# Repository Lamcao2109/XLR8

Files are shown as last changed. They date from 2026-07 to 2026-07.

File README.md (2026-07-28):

# XLR8 — WRO 2026 Future Engineers

Engineering documentation for **XLR8**, a self-driving LEGO SPIKE Prime vehicle built for the **World Robot Olympiad (WRO) 2026 — Future Engineers** category.

> CAD/3D-printable model files are in [`models/`](models/).

## Repository content

| Folder | Content |
|---|---|
| [`t-photos`](t-photos/) | Team photos (official + funny) |
| [`v-photos`](v-photos/) | 6 photos of the vehicle — front, back, left, right, top, bottom |
| [`video`](video/) | Links to the driving-demonstration videos (open + obstacle rounds) |
| [`schemes`](schemes/) | Electromechanical wiring diagram and annotated component photos |
| [`src`](src/) | Control software (hub + camera) |
| [`models`](models/) | 3D-printable/CAD parts (CAD source + STL/STEP + full render) |
| [`construction-guide`](construction-guide/) | Step-by-step build guide (rear camera → upper chassis → lower chassis → software) |
| [`other`](other/) | Supporting figures referenced from this document (mechanical design, iteration history, power & sensors, software & vision) |

---

## Table of contents

1. [Our team](#1-our-team)
2. [The robot](#2-the-robot)
3. [Mobility and Mechanical Design](#3-mobility-and-mechanical-design)
4. [Power and Sensor Architecture](#4-power-and-sensor-architecture)
5. [Software Architecture and Obstacle Strategy](#5-software-architecture-and-obstacle-strategy)
6. [Systems Thinking and Engineering Decisions](#6-systems-thinking-and-engineering-decisions)
7. [Repository / build instructions](#7-repository--build-instructions)
8. [Future Improvements](#8-future-improvements)
9. [Conclusion](#9-conclusion)

---

## 1. Our team

This repository documents the autonomous robot car developed by **XLR8** for the **2026 World Robot Olympiad Future Engineers** competition. The project was designed, built and programmed by a team of three students.

| Photo | Member | Role |
|---|---|---|
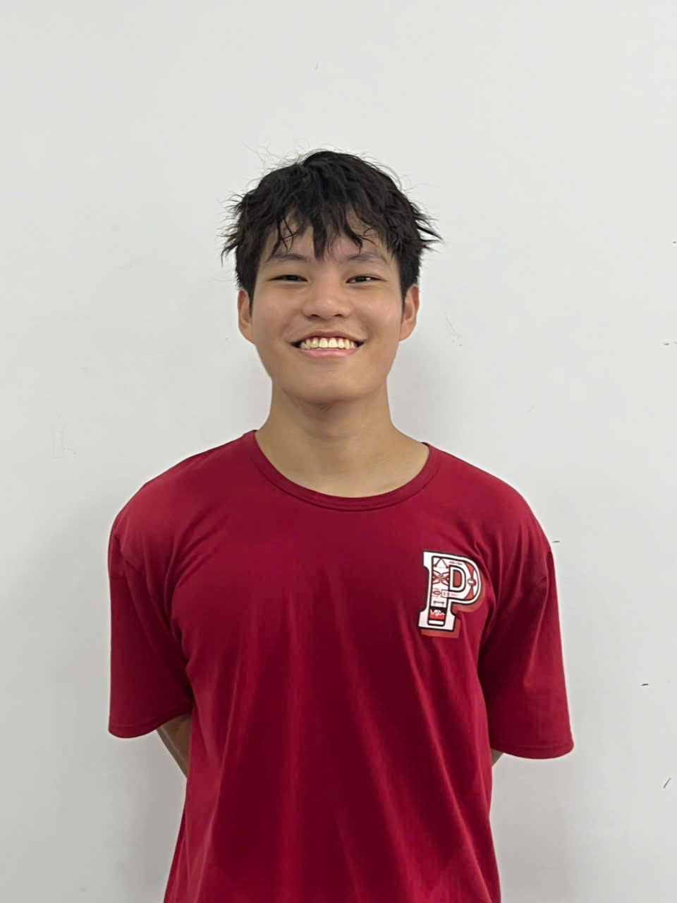
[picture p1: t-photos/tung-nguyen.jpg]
Tung Nguyen
|  | **Tung Nguyen (Philip)** | 17-year-old student from Vietnam. Responsible for documenting the team's development process and photography. Interests: engineering, physics, teamwork, volleyball, video games. |
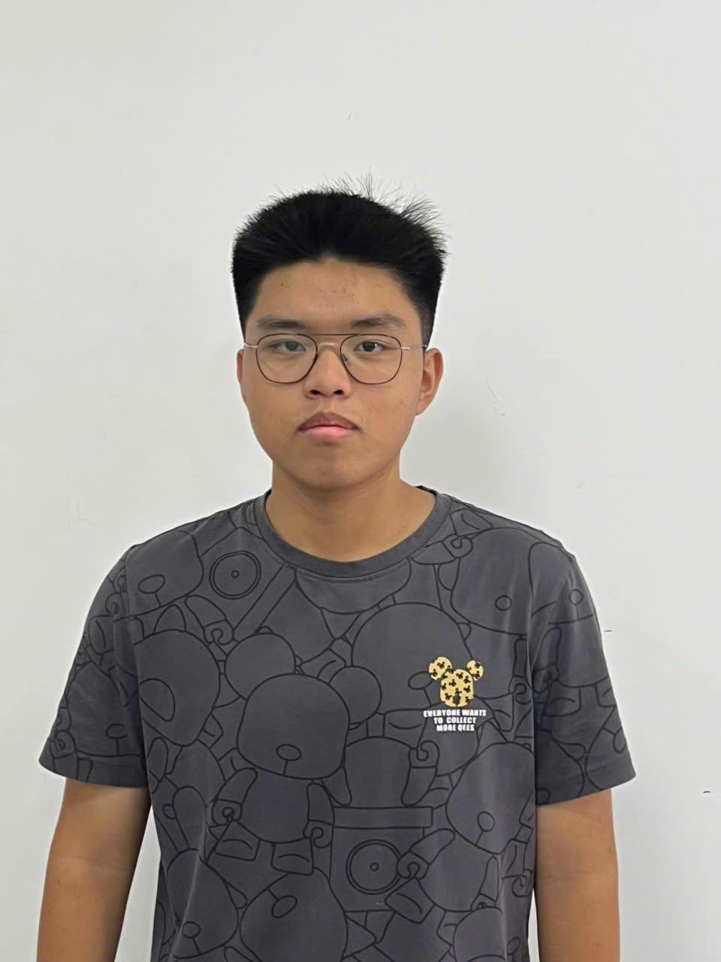
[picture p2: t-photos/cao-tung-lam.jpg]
Cao Tung Lam
|  | **Cao Tung Lam** | Lead mechanical builder — brings prior WRO experience (WRO 2023, 2024, 2025) and designed/assembled the chassis. |
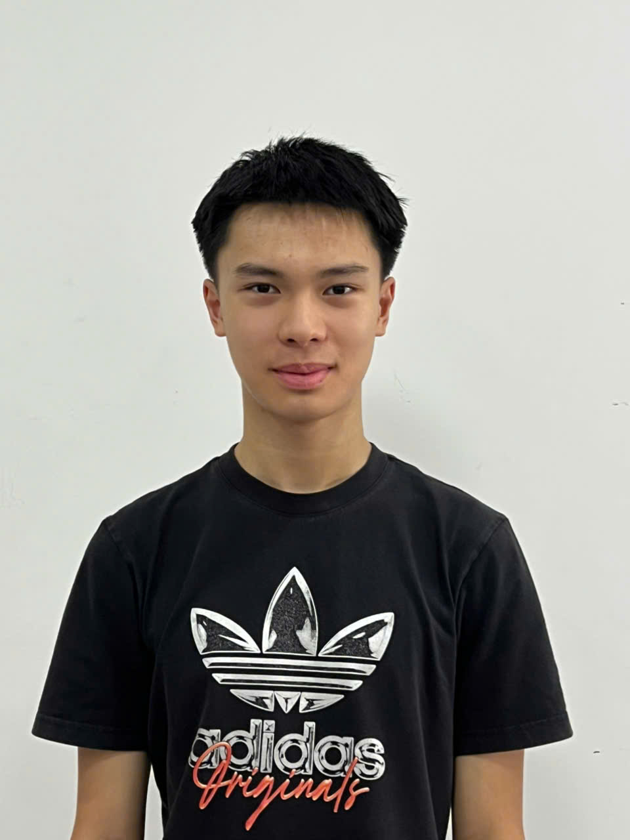
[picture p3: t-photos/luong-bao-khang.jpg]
Luong Bao Khang
|  | **Luong Bao Khang** | Senior WRO participant — competed at the international finals in 2023, 2024 and 2025. |

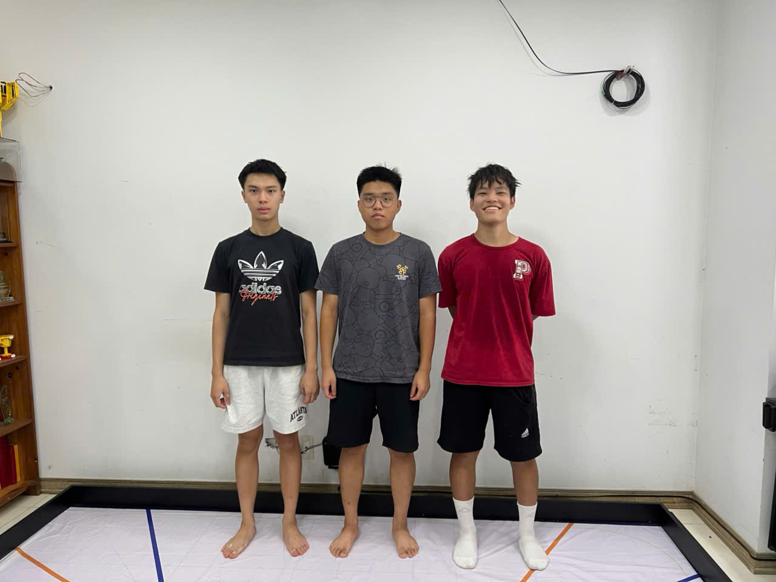
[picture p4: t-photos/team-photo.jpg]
Team photo


Last year's robot (which inspired this year's chassis) is documented at: https://github.com/uyennhu25/WRO_2025_Future_Engineers

## 2. The robot

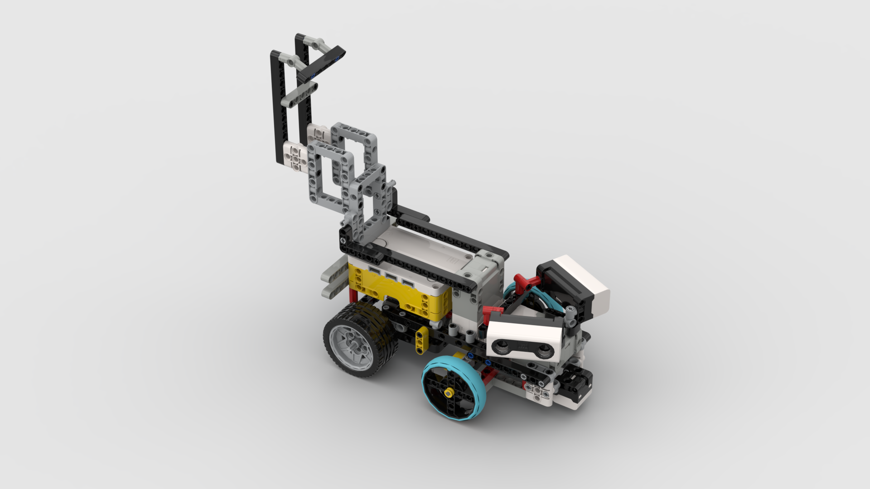
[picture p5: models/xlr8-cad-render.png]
Full CAD render


CAD source and 3D-printable parts for the assembly above are in [`models/`](models/).

| | | |
|---|---|---|
| Front | Back | Top |
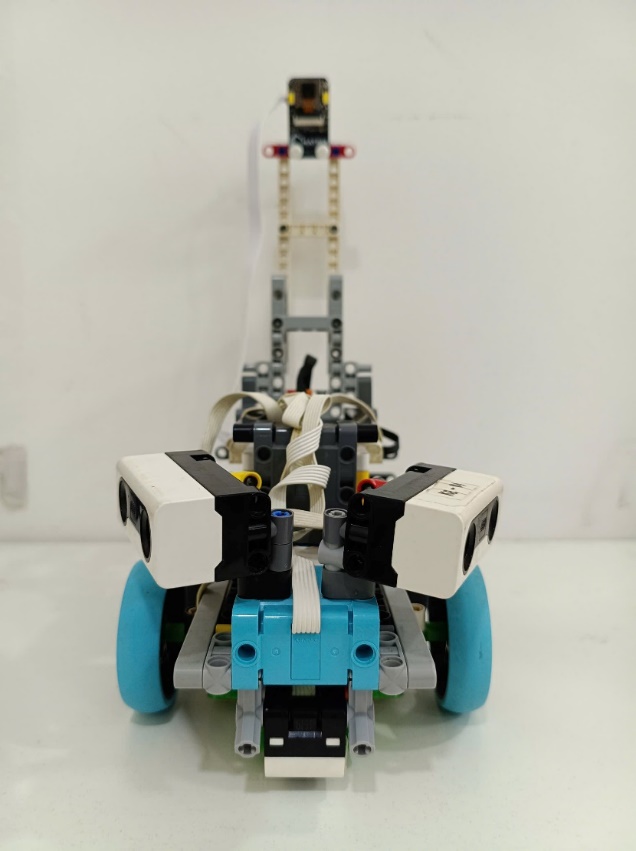
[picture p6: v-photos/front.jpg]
Front view
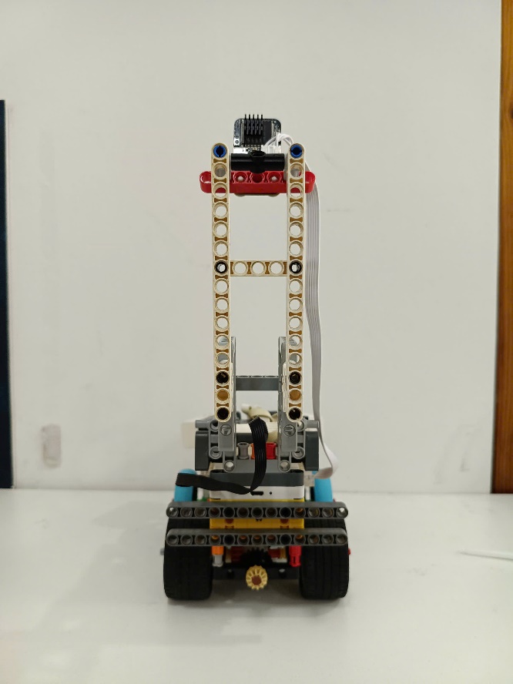
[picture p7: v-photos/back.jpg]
Back view
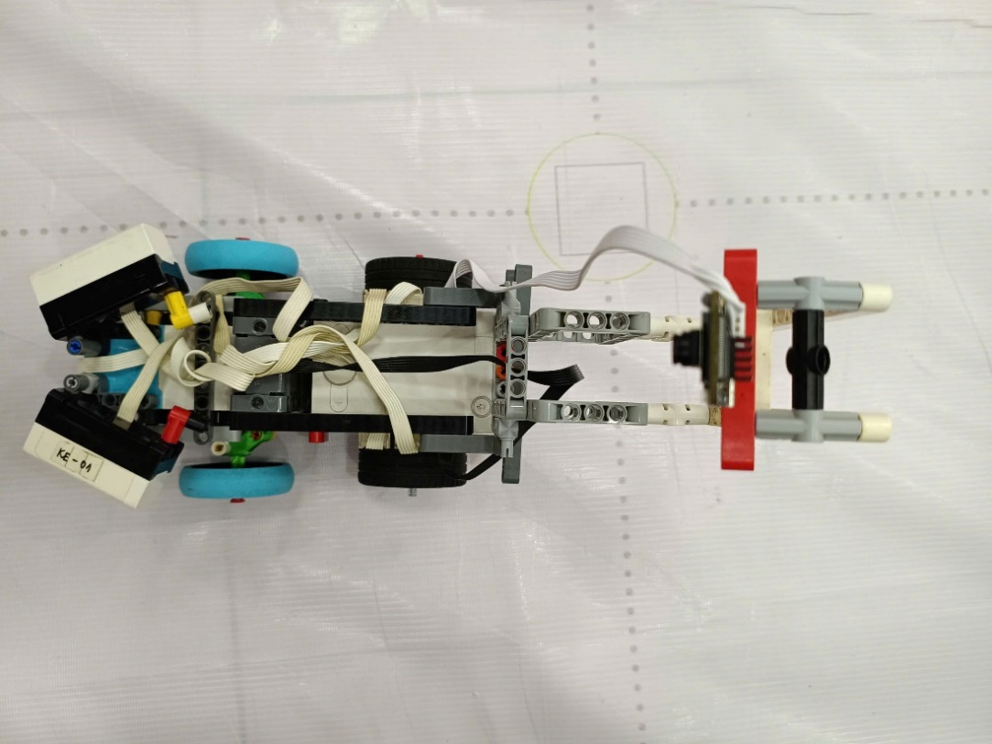
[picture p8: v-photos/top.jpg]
Top view
|  |  |  |
| Left | Right | Bottom |
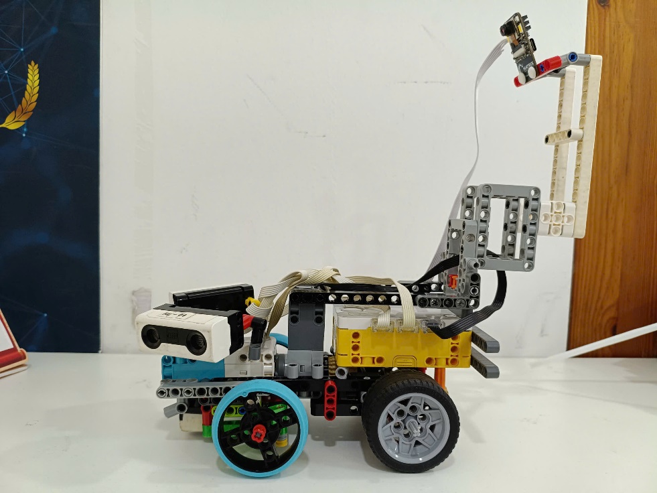
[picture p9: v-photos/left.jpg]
Left view
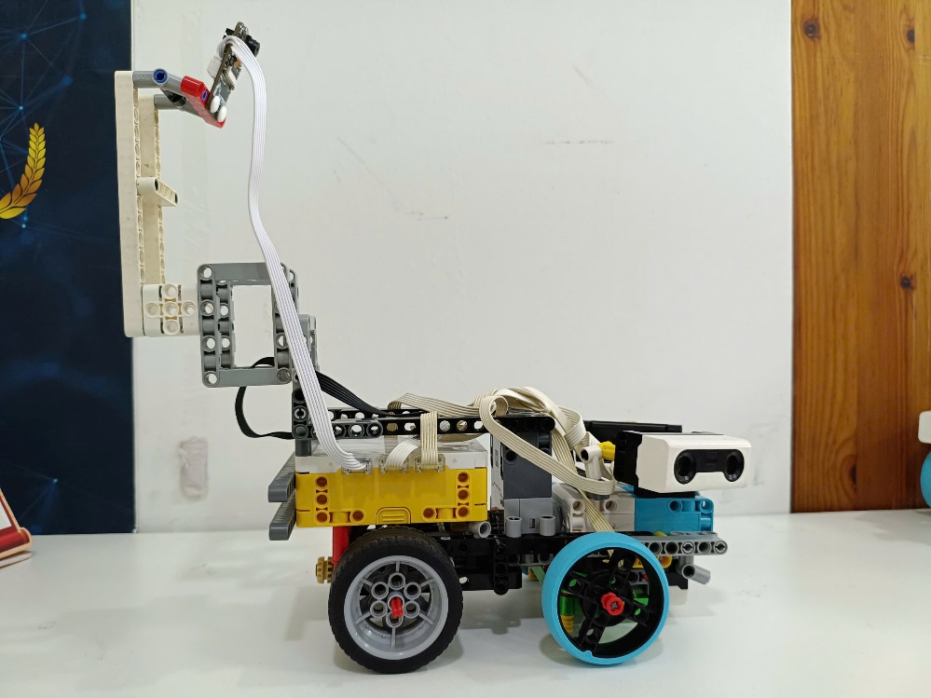
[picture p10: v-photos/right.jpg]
Right view
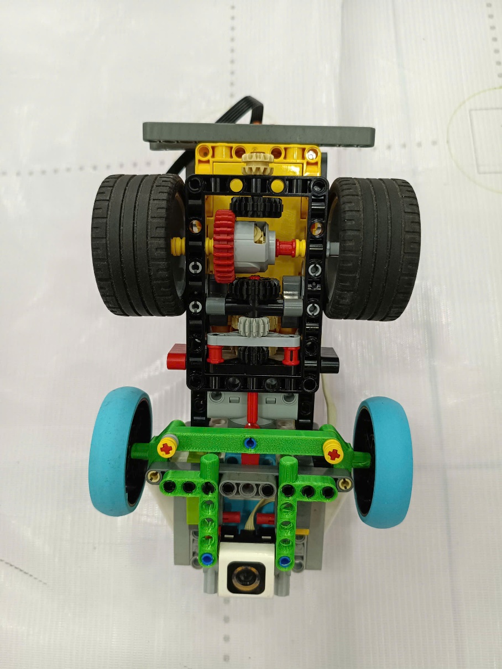
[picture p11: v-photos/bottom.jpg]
Bottom view
|  |  |  |

## 3. Mobility and Mechanical Design

### Design objective

The chassis was designed to remain stable, operate efficiently and make optimal use of available space: a balanced center of gravity for stability during sharp turns/acceleration and a steady camera platform, a lightweight structure to reduce motor load, and compact dimensions for maneuverability.

Lam (our lead builder) competed with a LEGO-based robot in WRO 2023, 2024 and 2025; that experience — and last year's robot — was the starting point for this year's chassis, which was then substantially redesigned.

### Overall chassis layout

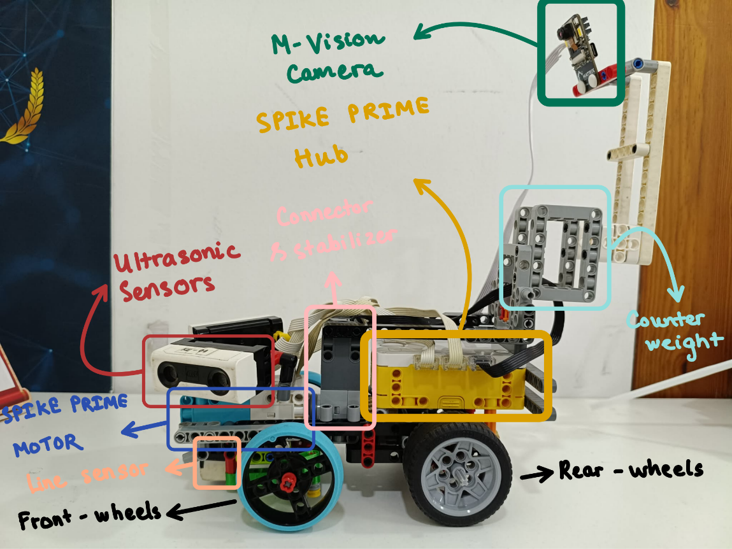
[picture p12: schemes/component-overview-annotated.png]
Component overview


The robot is divided into two main sections:

* **Main chassis** — LEGO SPIKE Prime Hub, drive/steer motors, ultrasonic sensors, line sensor, connector/stabilizer, wheel assemblies.
* **Rear-mounted camera assembly** — counterweight, camera support mast, M-Vision camera.

Unlike last year's design (camera mounted at the front, everything on one chassis), this year's robot elevates the camera on a rear mast:

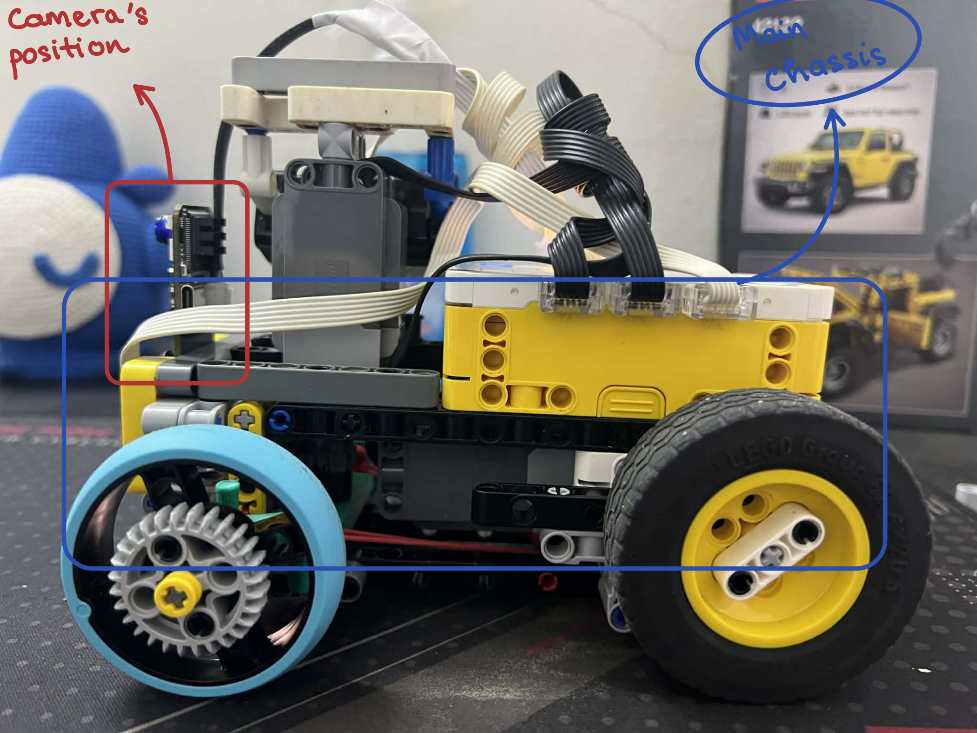
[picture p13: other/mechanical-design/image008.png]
Camera repositioning rationale


Relocating the camera to an elevated rear position gives the vision system a wider field of view, so the corridor and obstacles are detected earlier and more reliably, at the cost of having to keep the tall mast from destabilizing the car.

### Keeping the elevated camera from tipping the car

We ran a simple static-moment analysis, taking the rear-wheel ground contact line as the pivot, comparing the **overturning moment** created by the rear-mounted mast/counterweight assembly against the **restoring moment** created by the main chassis:

$$M_1 = \sum m_1 \times L_1 \qquad \text{(restoring moment, main chassis)}$$

$$M_2 = \sum m_2 \times L_2 \qquad \text{(overturning moment, rear assembly)}$$

The car does not tip as long as:

$$M_1 \ge M_2 \quad\Longleftrightarrow\quad \sum m_1 L_1 \ \ge\ \sum m_2 L_2$$

Because $\sum m_1 L_1$ is essentially fixed (motors/sensors/hub have fixed mass and position), the only lever we have is the rear assembly: we minimized both the mass $m_2$ and the distance $L_2$ of the rear assembly from the pivot. The box-shaped camera mount (most of the rear assembly's weight) sits as close to the pivot as practical, and the mount itself is a **closed-box structural member** that doubles as counterweight and torsional stiffener.

### What we kept from last year's robot

* **Chassis material** — LEGO Technic/SPIKE parts (lightweight, durable, modular, fast iteration) supplemented with custom **PLA 3D-printed** parts where no suitable LEGO part existed.
* **Wheel choice** — 62.3 mm Technic tires on the rear axle (larger diameter/width → better traction and acceleration) and 49.5 mm SPIKE Prime wheels on the front axle (smaller diameter → sharper steering response).

### Drive and steering mechanism

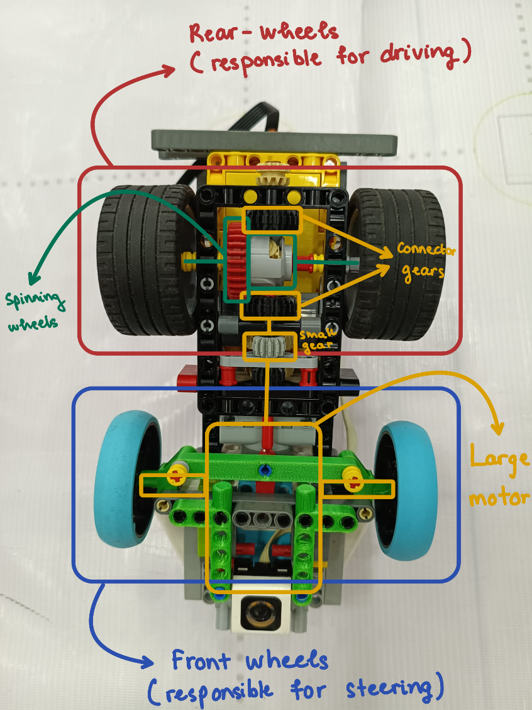
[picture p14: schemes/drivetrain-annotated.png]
Drivetrain


**Rear-wheel drive (RWD).** The rear wheels are powered by a LEGO SPIKE Prime Large Angular Motor through a small gear → two larger gears → final drive gears reduction; the front wheels only steer, driven by a second Large Angular Motor via UART-controlled servo positioning.

We deliberately rejected **front-wheel drive**, even though the drive motor sits over the front wheels and FWD would need no rear power transmission: combining steering and propulsion on the same wheels reduces steering precision and causes understeer in fast corners. Separating the two gives more predictable handling and simplifies implementing Ackermann geometry.

**Ackermann steering.** During a turn the inner and outer front wheels trace circles of different radii, so they need different steering angles (inner wheel turns sharper). Our linkage approximates this so all wheels roll with minimal lateral scrub, improving turn accuracy and reducing friction.

*The geometric reason: one turn, one centre.* When a vehicle corners without any wheel sliding sideways, every wheel travels along a circular arc, and all those arcs share a single centre — the instantaneous centre of rotation (ICR). A wheel rolls cleanly only when its axis points straight at the ICR, so the perpendicular from every wheel must pass through that one point. Our rear axle is fixed, so both rear wheels' axes lie on the same line, which forces the ICR onto the extension of that line. The two front wheels must then angle so their perpendiculars meet at that same spot — and because the inner front wheel sits closer to the ICR, it rides a tighter circle and needs a larger steering angle. That's the whole idea: the front wheels must not be parallel.

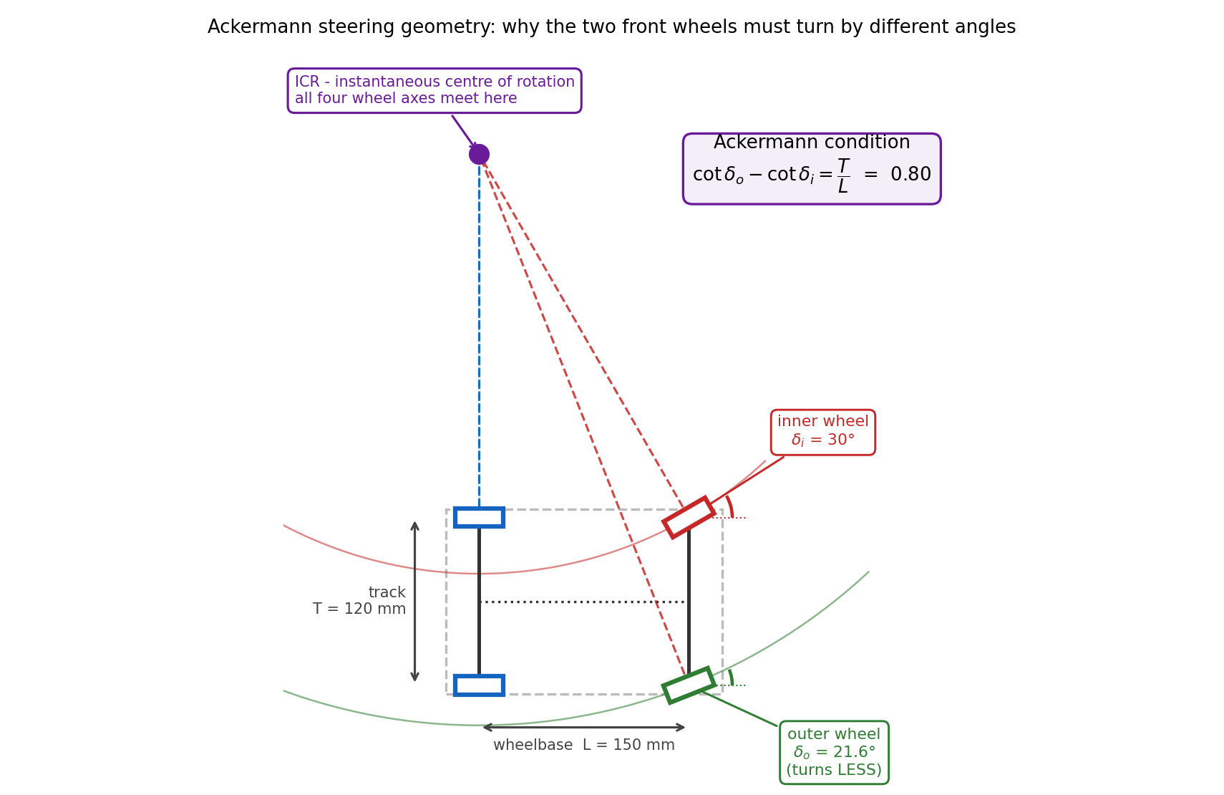
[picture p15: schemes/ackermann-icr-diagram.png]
Ackermann ICR diagram


*Figure — the ICR condition, worked numerically.* The dashed lines are the extended wheel axes: the rear pair (fixed, driven) meets the front pair exactly at the ICR, which is why the ICR always sits somewhere on the rear-axle line. For a wheelbase $L = 150$ mm and track $T = 120$ mm, an inner-wheel angle of $\delta_i = 30°$ requires an outer-wheel angle of $\delta_o = 21.6°$ — not $30°$. Plugging both into the condition confirms it: $\cot(21.6°) - \cot(30°) = 2.53 - 1.73 = 0.80 = T/L$. The two red/green arcs are the actual paths the inner and outer tyres trace; they're concentric about the ICR, which is the entire point — no tyre has to slip sideways to stay on its arc.

*The condition, stated exactly.* With wheelbase $L$, track $T$, and inner/outer steering angles $\delta_i$, $\delta_o$, requiring both perpendiculars to meet on the rear-axle line reduces to:

$$\cot(\delta_o) - \cot(\delta_i) = \frac{T}{L}$$

The cotangent form matters: the required angle difference isn't constant. At a gentle 10° steer our measured geometry differs by about 1°; at 30° (near full lock) it's over 8°. A design that just held both wheels parallel would be almost right while cruising and badly wrong exactly when it matters most — a tight corner or the parking manoeuvre.

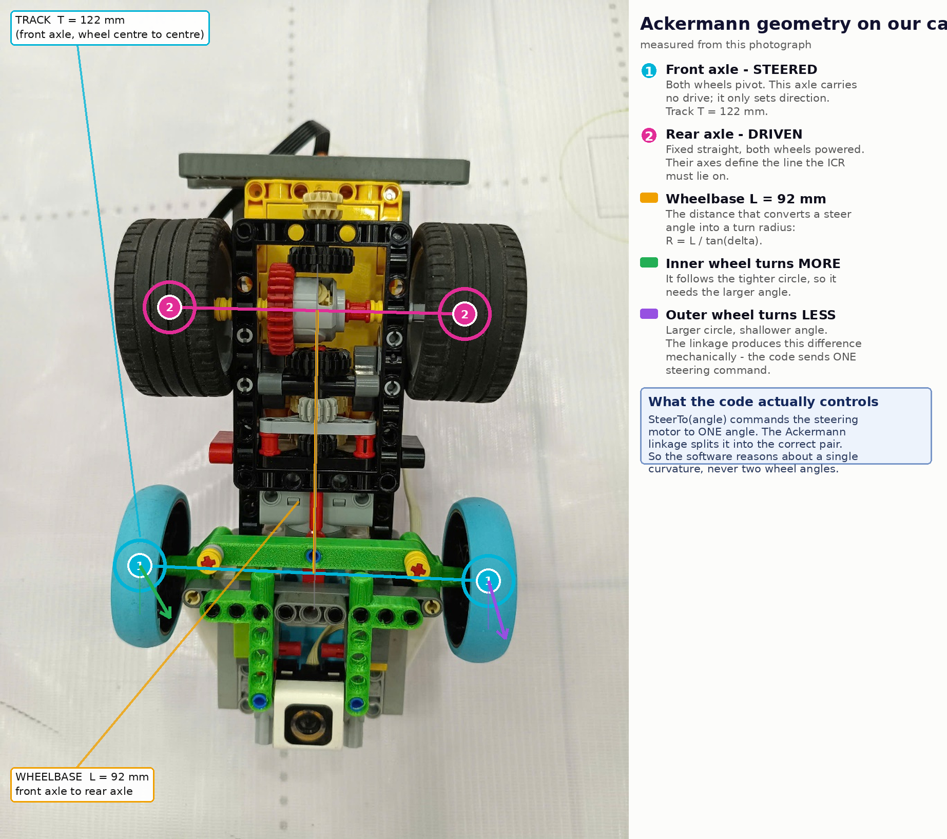
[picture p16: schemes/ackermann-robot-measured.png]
Ackermann geometry measured on our robot


*Figure — the same geometry on our own vehicle, measured from the underside.* Track $T = 122$ mm and wheelbase $L = 92$ mm, giving $T/L \approx 1.33$ — a shorter wheelbase relative to track than the worked example above, so our robot needs an even *larger* angle spread between the two front wheels for the same inner-wheel angle. The front axle (steered, undriven) only sets direction; the rear axle (fixed, driven) defines the line the ICR must lie on. The green arrow marks the inner wheel turning further, the purple arrow the outer wheel turning less — both driven by the single `SteerTo(angle)` command through the physical linkage, not computed separately in code.

*Why it matters for this robot specifically.* Violating the condition forces at least one tyre to scrub sideways instead of roll, which (1) wastes motor torque as friction/heat, slowing the car in corners, (2) wears the tyres unevenly, causing inconsistent lap times late in a run, and (3) makes the turn radius unpredictable — the car no longer follows the arc the steering angle implies. Every dead-reckoned manoeuvre in the code (the escape turn, corner assist, and above all the reverse arcs of the parallel park, §8) assumes a given steering angle produces a *repeatable* radius; Ackermann geometry is what makes that assumption true.

*What this means for the software.* The program never computes $\delta_i$ and $\delta_o$ — the linkage solves the Ackermann relationship mechanically, not the hub numerically. `SteerTo(angle)` sends one number to one steering motor, and the linkage geometry converts it into the correct pair of wheel angles automatically. This is why `CalibrateSteer()` (§5, Change 5) matters so much: since one command drives both wheels through a fixed linkage, the only thing the software has to get right is where the linkage's true centre lies — exactly what the end-stop sweep measures.

### Motor power tuning

We swept motor power at 60/85/100% over 20 test laps on the Open Challenge course, recording lap time, lap-completion rate and braking distance:

| Setting | Motor power | Avg lap time | Lap completion | Braking distance |
|---|---|---|---|---|
| A | 60% | 40.42 s | 95% | 4 cm |
| **B (chosen)** | **85%** | **23.34 s** | **85%** | **6 cm** |
| C | 100% | 18.78 s | 55% | 10 cm |

100% power was fastest but failed 45% of runs — worthless in competition, since a failed run scores zero. 85% power is only ~19.5% slower than 100% but far more reliable, so **85% power** was selected for both the Open and Obstacle rounds.

### Iterative build process

We built a working prototype first, tested on the real field, found concrete failures, and iterated. Photos of that progression are in [`other/iteration-history/`](other/iteration-history/) (version 1 → version 2 → final chassis).

## 4. Power and Sensor Architecture

### Sensor overview

| Sensor | Model | Qty | Purpose |
|---|---|---|---|
| Camera | Matrix Robotics M-Vision Cam (Type-C) | 1 | Lane/sign detection, corner detection |
| Ultrasonic | LEGO SPIKE Prime Ultrasonic Sensor | 2 | Left/right wall distance |
| IMU | Built into SPIKE Prime Hub | 1 | Angular velocity for heading estimation |
| Motor encoders | Built into SPIKE Prime motors | 2 | Distance measurement, steering calibration |
| Color/line sensor | SPIKE Prime color/distance sensor | 1 | Corner line (orange/blue) detection |

### Why each sensor was chosen

**Camera — Matrix Robotics M-Vision Cam.** Connects directly to the hub over Type-C and speaks the SPIKE Prime vision-sensor protocol, so no custom UART implementation or adapter board was needed (unlike an OpenMV Cam H7, a Raspberry Pi camera, or a USB webcam, all of which were considered and rejected for requiring extra hardware/wiring/power).

**Ultrasonic — LEGO SPIKE Prime Ultrasonic Sensor** (5–200 cm range, ~15° cone). Chosen over HC-SR04 (needs a separate microcontroller), ToF VL53L0X (shorter range, light-sensitive, pricier) and LiDAR (overkill, heavy, expensive) because it plugs directly into the hub.

**IMU — built into the hub.** We only read raw `hub.imu.angular_velocity(Axis.Z)`, feeding our own [Lagrange-interpolated heading estimator](#change-6--lagrange-interpolated-theta-from-angular-velocity) instead of the firmware's `hub.imu.heading()` (see §6). An external IMU (e.g. MPU-6050) would add weight, wiring and complexity for no benefit.

**Motor encoders.** Used for `DriveDeg()` (dead-reckoning distance), `CalibrateSteer()` (measuring the full steering range so "straight" is a measured fact, not an assumption) and `SteerTo()` (closed-loop steering angle).

**Color sensor.** Counts the orange/blue corner lines painted on the mat — 12 line events = 4 corners × 3 laps. Kept as a *dedicated* sensor rather than pulling corner counts out of the camera feed, since the camera is already busy with lane/sign detection.

### Power architecture

All components are powered from the SPIKE Prime Hub's own 7.3 V Li-Ion battery — one battery, simpler wiring, less weight.

| Component | Voltage | Current (typical) | Current (peak) | Power (typical) |
|---|---|---|---|---|
| SPIKE Prime Hub | 7.2 V | 1.0 A | 1.5 A | 7.2 W |
| M-Vision Camera | 5 V (Type-C) | 0.15 A | 0.3 A | 0.75 W |
| Ultrasonic ×2 | 5 V (from hub) | 0.04 A | 0.06 A | 0.2 W |
| Drive motors ×2 | 7.2 V | 1.0 A | 2.0 A | 7.2 W |
| **Total** | | **2.19 A** | **3.86 A** | **15.35 W** |

Peak current (3.86 A) occurs during acceleration and hard cornering; the hub's battery comfortably covers the ~3-minute competition round.

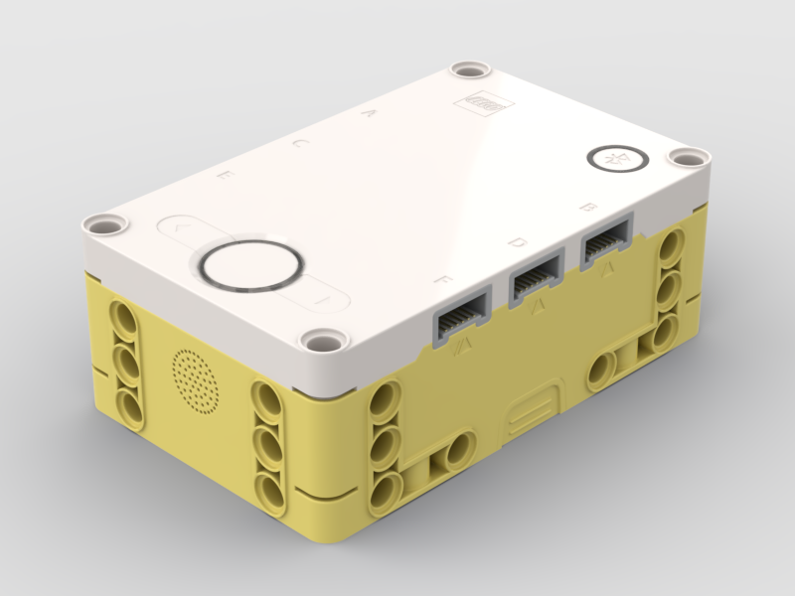
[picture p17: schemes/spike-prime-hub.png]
SPIKE Prime Hub


### Electromechanical wiring diagram

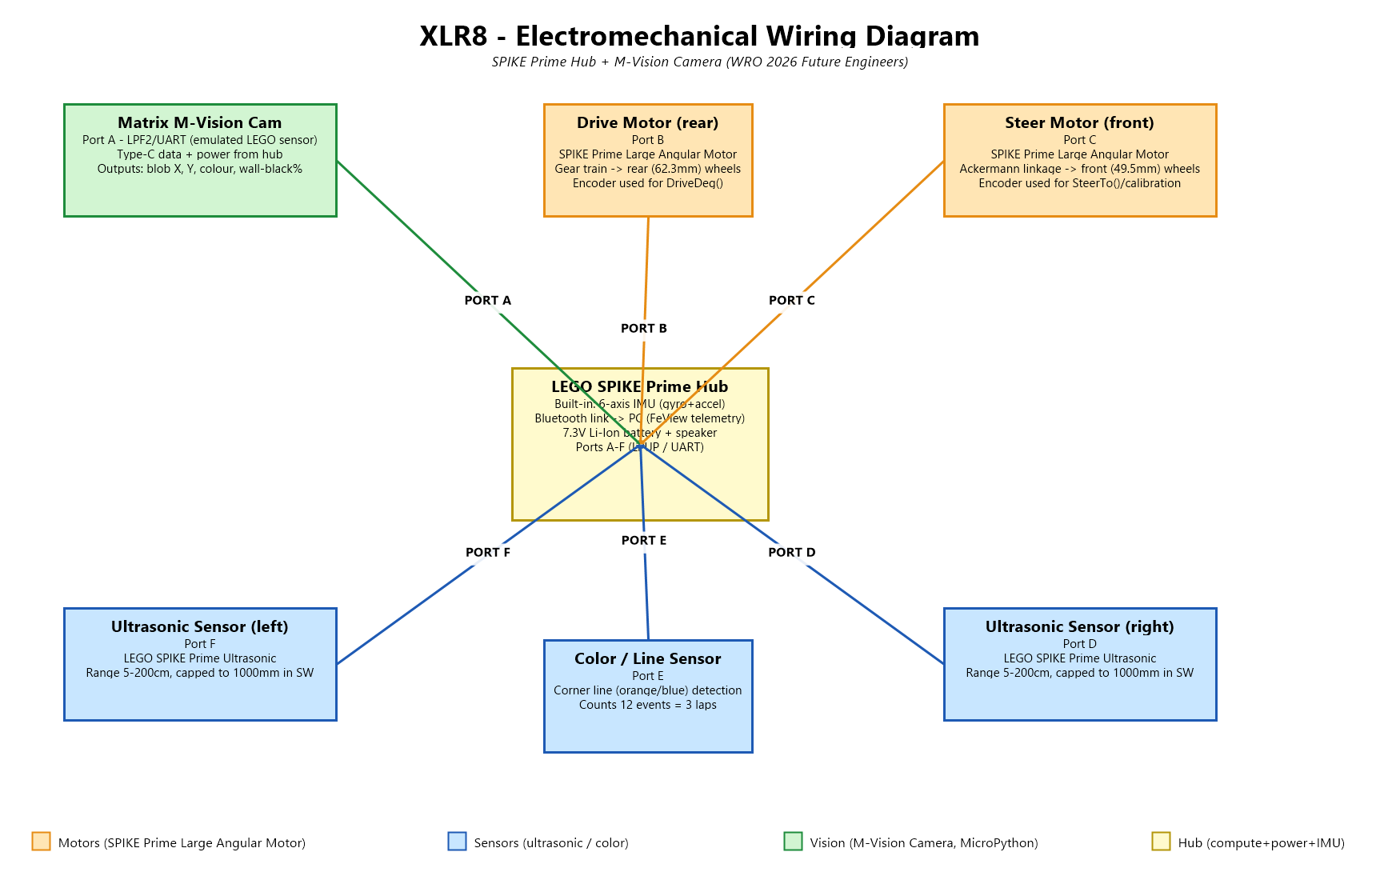
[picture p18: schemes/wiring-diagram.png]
Wiring diagram


| Hub port | Device |
|---|---|
| **A** | M-Vision Camera (LPF2/UART, emulated LEGO sensor over Type-C) |
| **B** | Drive motor → rear wheels |
| **C** | Steer motor → front wheels (Ackermann linkage) |
| **D** | Ultrasonic sensor (right) |
| **E** | Color/line sensor |
| **F** | Ultrasonic sensor (left) |
| *(internal)* | 6-axis IMU, Bluetooth (telemetry to PC via `FeView.py`), 7.3 V Li-Ion battery, speaker |

Ports/pins are taken directly from [`src/hub/FeFunctions.py`](src/hub/FeFunctions.py) so this diagram always matches the code.

### Calibration

* **Camera** — auto-gain and auto-white-balance are **disabled** (mandatory, otherwise the camera re-derives its own color space every time lighting changes and every threshold breaks); color thresholds and LAB values are tuned for the competition mat.
* **Ultrasonic** — raw reads are never trusted directly: `-1` (no echo) and out-of-range values are capped before use, so a single bad read can't throw the controller into full-lock steering.
* **Steering** — `CalibrateSteer()` sweeps to both end-stops, measures the true range from the encoder, and resets zero to the exact middle, run before every start.
* **Gyro bias** — `ThetaCalibrate()` measures the gyro's standing bias for 0.8 s before the robot moves (a real gyro at rest does not read exactly zero), so bias can't masquerade as slow rotation for three minutes.

### Failure modes and mitigation

| Sensor | Failure mode | Mitigation |
|---|---|---|
| Camera | Glare/reflections cause false positives | Density + aspect-ratio blob filters |
| Camera | Type-C connection issue | Re-seat cable; LPF2 NACK-heartbeat watchdog auto-reconnects |
| Ultrasonic | `-1` reading (no echo) | Capped to a safe large value before use |
| Ultrasonic | Open-side reading (very large) | Capped in `SteerClear`/`SteerOpen` before use |
| Ultrasonic | Distance < 150–200 mm (emergency) | Error forced to a large ± value to peel away immediately |
| IMU | Heading drift over 3 laps | Lagrange integrator + bias calibration (§6) |
| IMU | Gyro hiss while stationary | 0.5 deg/s deadband |
| Encoders | Steering "zero" drifts | `CalibrateSteer()` runs before every start |
| Color sensor | Corner misdetection | Counts exactly 12 events (4 corners × 3 laps), ignores extras |

## 5. Software Architecture and Obstacle Strategy

### The task, in software terms

WRO's Future Engineers task is really three problems stacked: the **Open Challenge** (3 laps around a square island, driving direction and corridor widths randomised before the run), the **Obstacle Challenge** (same 3 laps, but red signs must be passed on their right and green signs on their left), and **parallel parking** into a bay barely longer than the car.

Two rules shape every line of code:

1. **Car steering** — driving and steering are separate actuators; the car can never pivot in place, so every correction is a curve that must start early (`Forward()`/`Drive` vs `SteerTo()`/`Steer`).
2. **The run is ~3 minutes and twelve 90° corners long**, so any error that accumulates with time is multiplied by three laps.

The software runs on two computers: the **hub** runs Pybricks — [`FeFunctions.py`](src/hub/FeFunctions.py) (shared functions), [`FeOpen.py`](src/hub/FeOpen.py) and [`FeObstacle.py`](src/hub/FeObstacle.py) (the two competition programs), [`FeView.py`](src/hub/FeView.py) (telemetry) — and the **camera** runs its own MicroPython program: [`main.py`](src/camera/main.py) (vision) and [`LPF2.py`](src/camera/LPF2.py) (transport, emulating a LEGO sensor over UART).

`FeOpen.py` is intentionally simpler than `FeObstacle.py`: the Open Challenge has no signs to dodge and no parking, so it only needs `SteerOpen()` for wall-centring plus the same 12-line-event lap counter.

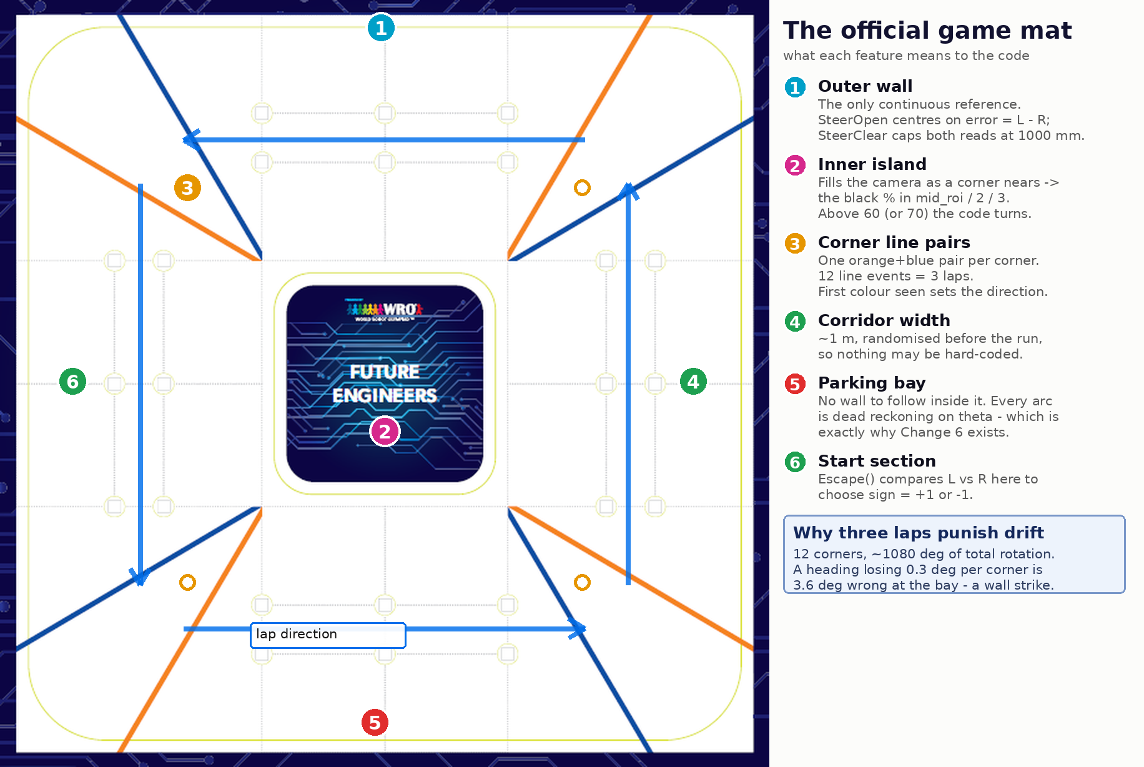
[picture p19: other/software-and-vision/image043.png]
Official game mat, annotated


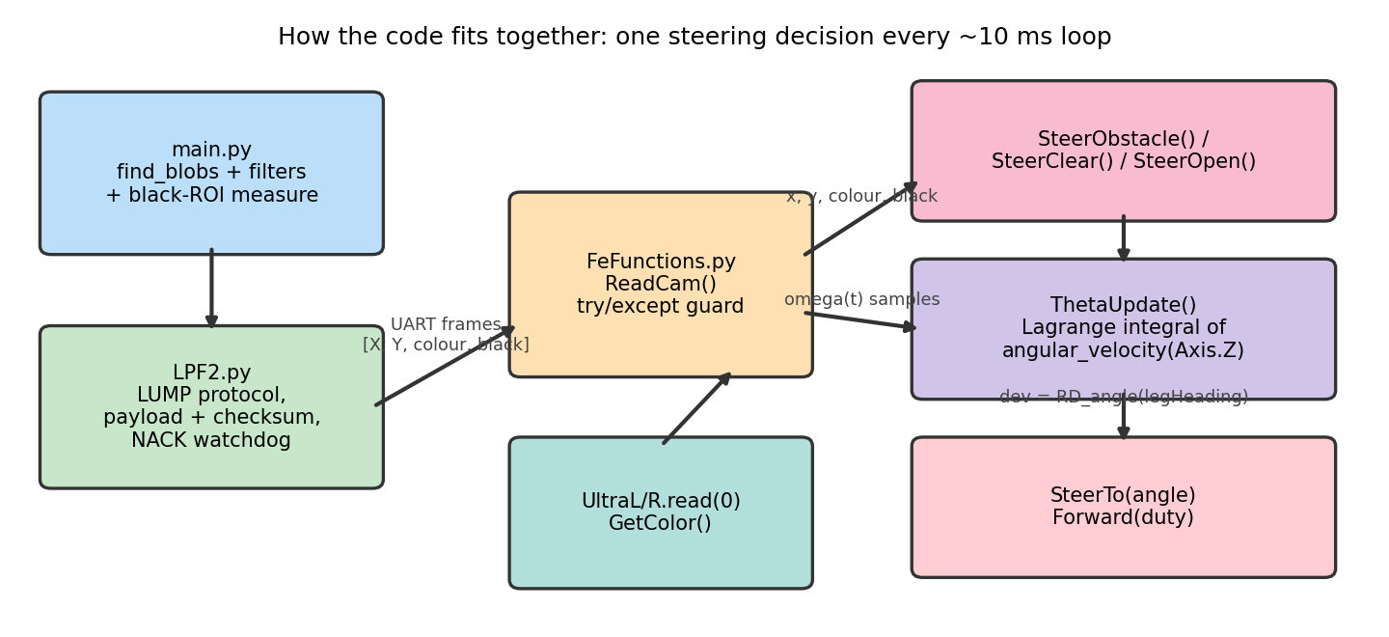
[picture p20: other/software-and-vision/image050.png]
How the modules fit together


### Version 0 — the naive first version

One `find_blobs()` call with a single red/green threshold over the whole frame; the hub steered proportionally on `error = Left − Right` between the two ultrasonics, nudged toward a sign's fixed pixel x-target when one appeared, and counted corner lines with `GetColor()`. Heading came straight from `hub.imu.heading()`. It could finish an empty lap on a good day — then we added signs and changed the lighting.

### Problem → Change log

We didn't design the perfect program on paper — we wrote something that drives at all, then let the field tell us what was wrong. Every practice run produced a concrete failure; every failure became a numbered change.

**Problem 1 — The camera saw signs that weren't there.** A single red threshold over the full frame caught reflections, glare, and objects beyond the field; a sign's actual color also shifts with distance and lighting.

**Change 1 — Mask, multiply thresholds, filter blobs.** `main.py` blacks out the top strip and the vehicle's own footprint before `find_blobs()` runs; red is matched by three separate LAB thresholds (bright/darkened/heavily-darkened); surviving blobs must be dense (≥50–65% of their bounding box — solid signs vs. ragged reflections), have area > 200 px, and be taller than wide (aspect ratio < 0.9, since signs are standing pillars). Among survivors, the lowest one in frame (largest `cy`) is the closest, dodged first.

**Problem 2 — The dodge came too late and too hard.** A fixed pixel target ignores a far sign, then demands a violent full-lock swerve once it's close.

**Change 2 — Ramp the target with distance (`TargetX()`).** The steering target slides linearly from a mild "far" value to the full dodge value as the sign's y-coordinate (a distance proxy) grows, so the correction starts seconds early and ends as a smooth arc. The steering limit is staged too (20° far, 40° close).

**Problem 3 — Ultrasonic readings lie two different ways.** A missed echo returns `-1`; an open gap in the inner wall can read far past the corridor width — both send the centring controller into nonsense.

**Change 3 — Cap readings, split the controller.** Bad/`-1` reads are capped before use. `SteerOpen()` (open round, `Kp = 0.018`) and `SteerClear()` (obstacle round, larger `Kp`, forces the error to a hard ± value if either side drops below 150 mm) are separate functions. Corner initiation gets its own cue: `main.py` measures how much **black** (the wall) fills three horizontal ROIs; above a threshold, the code forces a hard turn — the wall itself is the corner detector.

**Problem 4 — Corner logic fired mid-corridor.** A hard sign-dodge can swing the body 40–50° off-axis; mid-swing the camera faces the outer wall and the black% spikes, triggering a false corner turn — and once rotated far enough, left/right readings effectively swap.

**Change 4 — The `legHeading` gyro filter.** `FeObstacle.py` tracks `legHeading = i × sign × 90`, the ideal corridor axis. Every loop computes `dev = RD_angle(legHeading)`. If `|dev| > 15°` (`GYRO_FLIP`) the car is judged rotated off-axis: the controller stops trusting L/R centring and instead flips/forces the error to bring `dev` back toward zero (whose sign also fixes the swapped-readings case).

**Problem 5 — The steering had no idea where "straight" was.** A motor encoder only knows relative angles, so "zero" at boot could mean anything, and a constant curve gets inherited by the whole run.

**Change 5 — End-stop calibration + a servo loop.** `CalibrateSteer()` sweeps to both stops, measures the range, and resets zero to the middle. `SteerTo(angle)` servos through a clamped output and a clamped target; `STEER_LOAD_CAP = 70` keeps the motor from stalling.

**Problem 6 — Three laps of noise poisoned the heading (the big one).** By this point `legHeading`, the escape turn, and the whole parking sequence all read `hub.imu.heading()`. That number is itself an internal integration of the gyro, and it accumulates vibration, small impacts and sensor-fusion micro-corrections — invisible on lap 1, several degrees wrong by lap 3.

**Change 6 — Lagrange-interpolated theta from angular velocity.** See [§6](#6-systems-thinking-and-engineering-decisions) for the full derivation.

**Problem 7 — Parking is dead reckoning, and dead reckoning needs a perfect angle.** The parking sequence is a fixed choreography of arcs with nothing inside the bay to correct against; a drifted heading turns a small entry-angle error into a collision with the bay limiter.

**Change 7 — Theta-driven escape and parking choreography.** `Escape()`, `GyroDeg`, `GyroColor`, `GyroAcc` and `GyroToWall` all read `Heading()` and call `ThetaUpdate()` every loop iteration (including inside blind manoeuvres), `ThetaReset()` replaces `hub.imu.reset_heading()`, and a 0.5 deg/s deadband stops the integrator creeping before the run starts.

### The camera side (`main.py` + `LPF2.py`)

`main.py` configures the sensor to QVGA RGB565 with auto-gain/auto-white-balance **off** (mandatory), applies the Change-1 masks and filters, runs `find_blobs`, measures the wall black-percentage in three ROIs, and packs `[X, Y, colour, black]` for the hub. `LPF2.py` implements LUMP (the LEGO UART Message Protocol) so the hub sees a genuine LEGO sensor: it handshakes at 2400 baud, then both sides jump to 115200 baud; a NACK-heartbeat watchdog declares the link dead (and re-initialises) if 8 expected heartbeats go missing, turning a brown-out into a ~2 s reconnect instead of a dead run. `FeFunctions.ReadCam()` wraps the read in try/except, degrading a glitch into one blind control cycle instead of a crash.

### End-to-end control loop

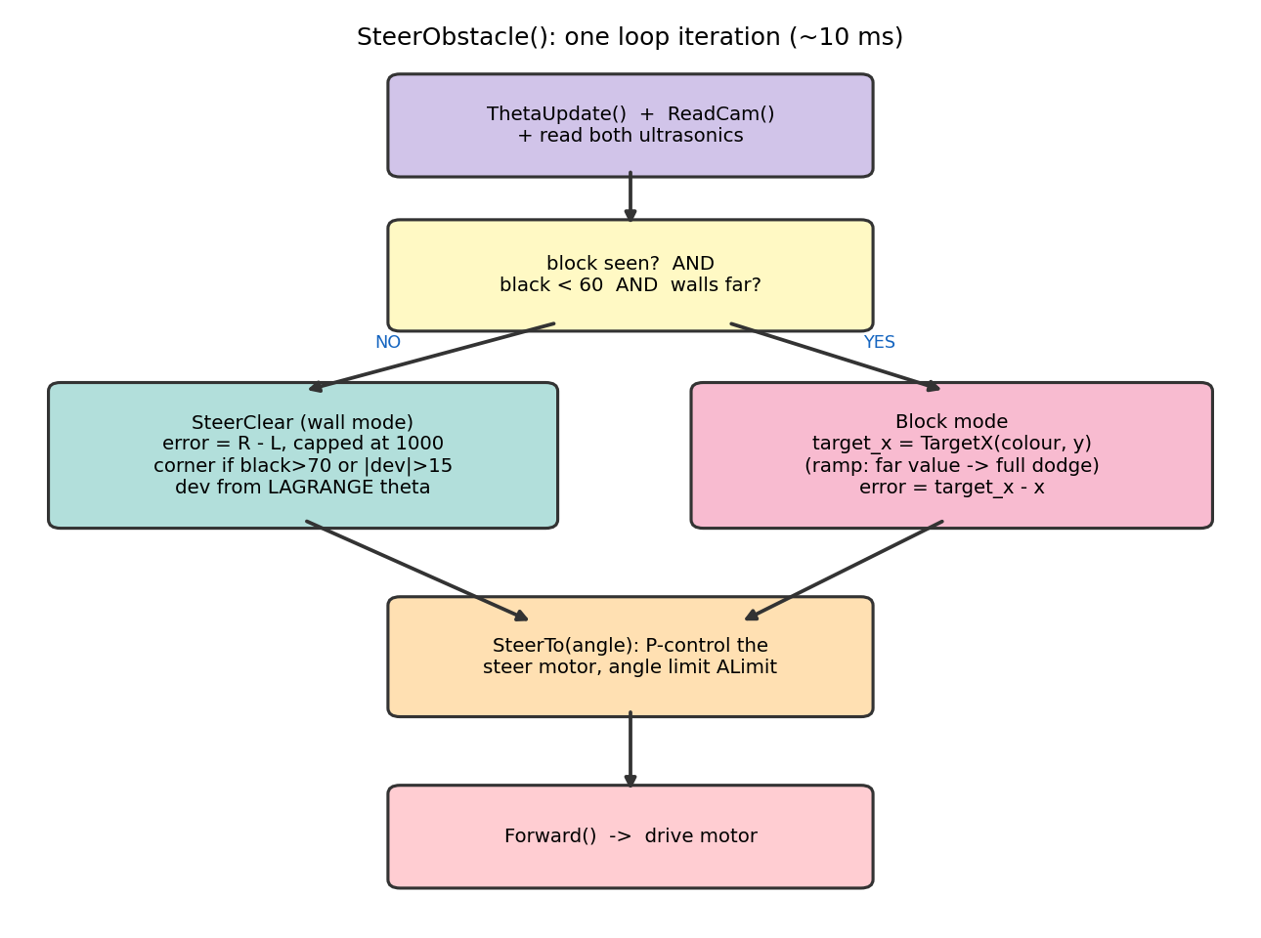
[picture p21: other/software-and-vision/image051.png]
One SteerObstacle() cycle


Each obstacle-round loop: `ThetaUpdate()` advances the heading integral → `ReadCam()` fetches `[X, Y, colour, black]` → ultrasonics are read and capped. If a sign is visible and no wall emergency is active, `TargetX` ramps the pixel target and `SteerTo` servos toward it under a staged angle limit; otherwise `SteerClear` centres between the capped wall distances, with `dev = RD_angle(legHeading)` (computed from the Lagrange theta) vetoing corners at the wrong time. `FeObstacle.py` counts twelve colour-line events to know when three laps are done, then hands off to parking.

## 6. Systems Thinking and Engineering Decisions

### Why interpolate at all?

We only know the angular velocity ω at discrete, unevenly-spaced instants $t_0 < t_1 < t_2 < t_3$ (loop jitter from the camera read, Bluetooth and garbage collection means the spacing is *not* a clean 10 ms), but we need the integral of the continuous signal between them. Every numerical integration method secretly assumes a model of what happens between samples — rectangle-sum assumes constant, trapezoid assumes a straight line. During a corner, yaw rate ramps from 0 to 100+ deg/s and back inside half a second, so that assumption matters a lot.

### Change 6 — Lagrange-interpolated theta from angular velocity

Instead of trusting the firmware's pre-integrated, pre-filtered `hub.imu.heading()`, we integrate the raw angular velocity ω(t) = `hub.imu.angular_velocity(Axis.Z)` ourselves, fitting the unique cubic **Lagrange interpolating polynomial** through the last 4 samples $(t_i, w_i)$:

$$L_i(t) = \prod_{j \ne i} \frac{t - t_j}{t_i - t_j} \qquad\qquad P(t) = \sum_{i=0}^{3} w_i\, L_i(t)$$

Each $L_i$ equals 1 at its own node and 0 at the other three, so $P(t)$ reproduces every sample exactly and is 4th-order accurate (the interpolation error scales with the 4th derivative of the true ω(t)). Node times appear explicitly in the formula, so **uneven spacing costs nothing** — exactly what a jittery loop needs.

Rather than evaluate $P(t)$ pointwise and approximate the integral with a quadrature rule, we build the same cubic in **Newton divided-difference form** and integrate it exactly. Divided differences $d_0..d_3$ give:

$$P(t) = d_0 + d_1(t-t_0) + d_2(t-t_0)(t-t_1) + d_3(t-t_0)(t-t_1)(t-t_2)$$

which we expand into ordinary coefficients $c_0..c_3$ and integrate with a plain antiderivative — the integral of a cubic is just another polynomial, so this is exact arithmetic, not an approximation:

$$\int_{t_2}^{t_3} P(t)\,dt \;=\; F(t_3) - F(t_2), \qquad F(x) = c_0 x + \tfrac{c_1}{2}x^2 + \tfrac{c_2}{3}x^3 + \tfrac{c_3}{4}x^4$$

Each loop advances theta by this exact integral over only the newest interval $[t_2, t_3]$ — no quadrature nodes, no magic constants.

Simulating a 3-lap run with realistic 2 deg/s gyro noise and jittery sampling:

| Integration method | Model between samples | Order | 3-lap error |
|---|---|---|---|
| Rectangle sum | constant | 1st | 0.21° |
| Trapezoid | straight line | 2nd | 0.13° |
| **Lagrange (N=4), exact cubic integral** *(ours)* | cubic | 4th | **0.02°** |

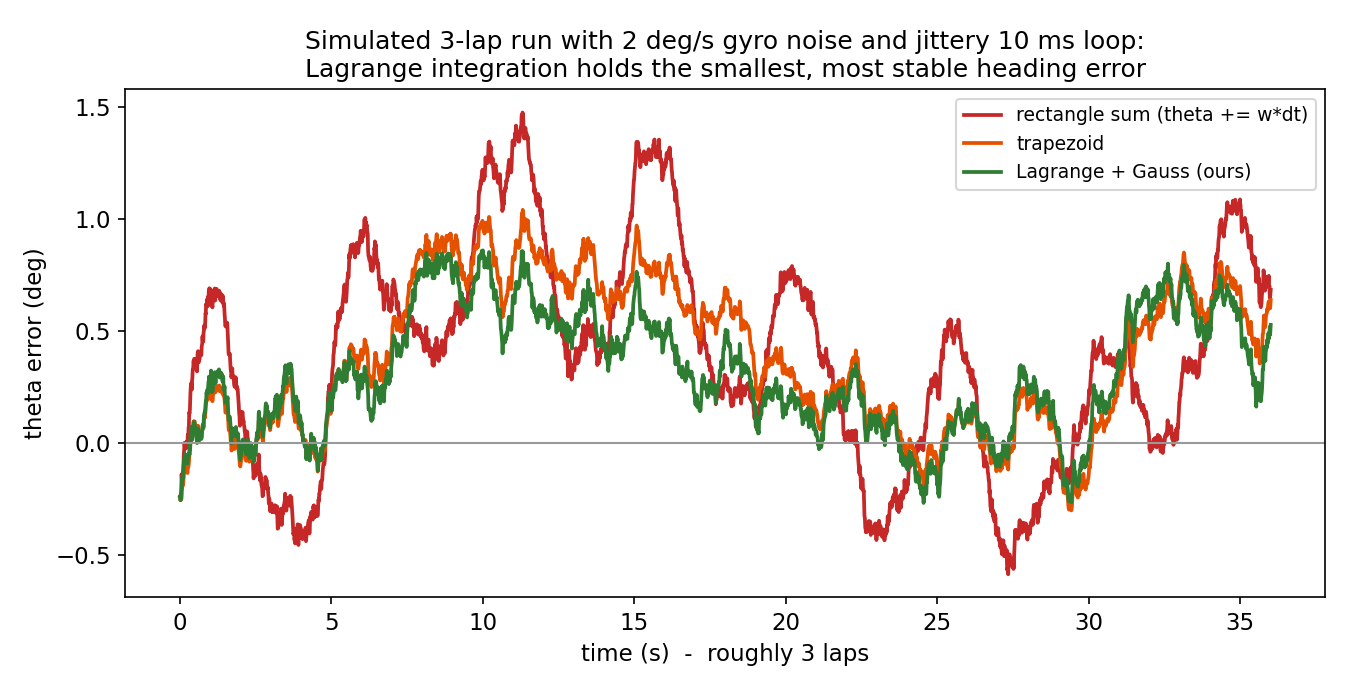
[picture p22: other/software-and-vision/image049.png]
Heading error over three laps


Three mechanisms explain the improvement:

1. **Noise averaging** — a corrupted sample doesn't enter the integral raw; the cubic through it and its 3 neighbours is only partly pulled toward the outlier.
2. **Bias removal** — `ThetaCalibrate()` measures our own gyro bias for 0.8 s under actual run conditions, instead of trusting factory calibration.
3. **No wrap, no fusion jumps** — theta is a plain unwrapped float (3 clockwise laps read ≈ −1080°), so angle arithmetic never sees a discontinuity, and no black-box sensor-fusion correction can step the value mid-corner.

The cost is honest: ~40 floating-point multiplications per loop (trivial at 100 Hz) and a 0.5 deg/s deadband that only ignores rotations slower than the vehicle can meaningfully make.

```python
# src/hub/FeFunctions.py (excerpt)
def _integrate_cubic(ts, ws):
    # exact integral of the cubic through 4 points, over [ts[2], ts[3]]
    t0, t1, t2, t3 = ts
    w0, w1, w2, w3 = ws

    d0 = w0
    d1 = (w1 - w0) / (t1 - t0)
    d12 = (w2 - w1) / (t2 - t1)
    d2 = (d12 - d1) / (t2 - t0)
    d23 = (w3 - w2) / (t3 - t2)
    d3 = ((d23 - d12) / (t3 - t1) - d2) / (t3 - t0)

    c3 = d3
    c2 = d2 - d3 * (t0 + t1 + t2)
    c1 = d1 - d2 * (t0 + t1) + d3 * (t0*t1 + t0*t2 + t1*t2)
    c0 = d0 - d1 * t0 + d2 * t0*t1 - d3 * t0*t1*t2

    def F(x):
        return ((((c3 * 0.25 * x + c2 / 3.0) * x + c1 * 0.5) * x) + c0) * x

    return F(t3) - F(t2)

def ThetaUpdate():
    global _theta
    t = theta_clock.time() / 1000.0
    w = hub.imu.angular_velocity(Axis.Z) - _omega_bias
    if -OMEGA_DEADBAND < w < OMEGA_DEADBAND:
        w = 0.0
    if _theta_ts and t <= _theta_ts[-1]:
        return _theta
    _theta_ts.append(t); _theta_ws.append(w)
    if len(_theta_ts) > THETA_N:
        _theta_ts.pop(0); _theta_ws.pop(0)
    n = len(_theta_ts)
    if n == 4:
        _theta += _integrate_cubic(_theta_ts, _theta_ws)
    elif n >= 2:
        _theta += 0.5 * (_theta_ws[-1] + _theta_ws[-2]) \
                      * (_theta_ts[-1] - _theta_ts[-2])
    return _theta
```

Full source: [`src/hub/FeFunctions.py`](src/hub/FeFunctions.py).

### Parking: the manoeuvre with no sensors

Everything up to this point has a reference to correct against — a wall, a line, an island. **Parking has none of them.** Once alongside the bay, the ultrasonics are too close/low to range usefully, the camera looks along the wall rather than at anything measurable, and the bay is entered backwards. The manoeuvre is therefore pure dead reckoning: fixed arcs, each driving a measured encoder distance while servoing the steering to hold a heading taken from `Heading()`.

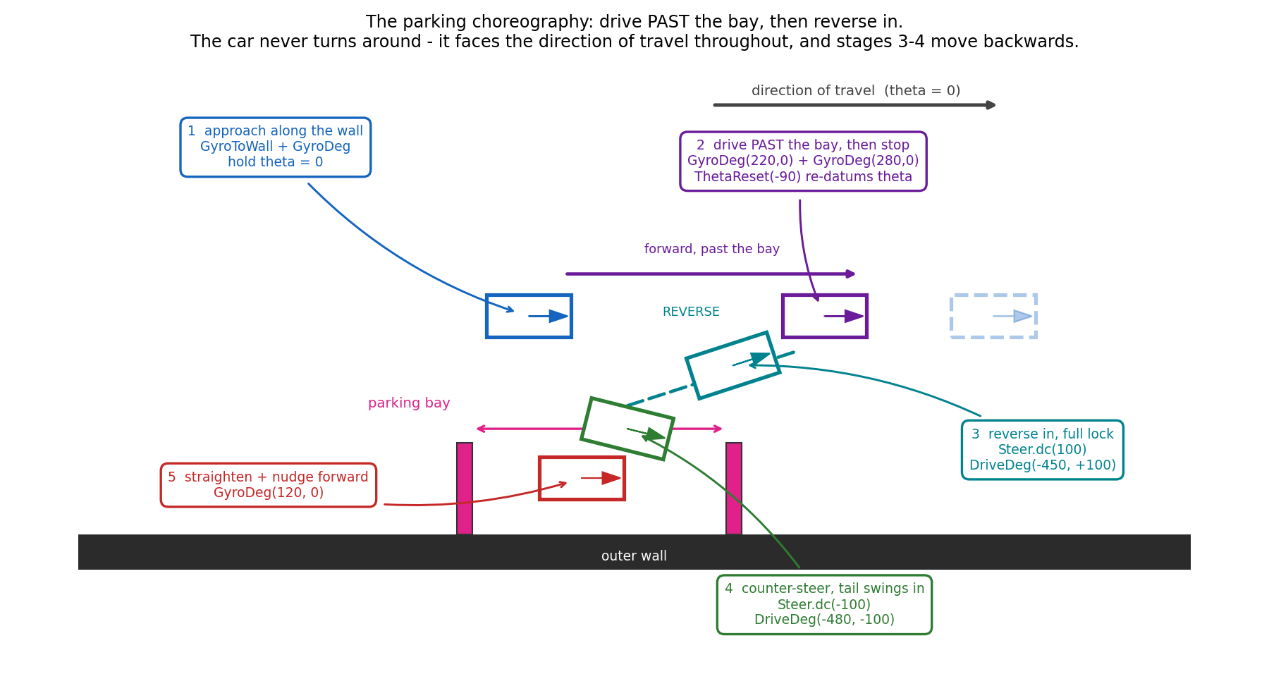
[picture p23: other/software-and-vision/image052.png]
Parallel parking sequence


1. **Onto the bay straight** — after the 12th corner-line event, a staged `GyroAcc` + `GyroDeg` carry the car around the final corner holding a heading around `sign × 1168°` (3 laps of accumulated rotation + the approach angle), then a short manual steer-flick straightens the car against the wall.
2. **Find the bay by its two limiter walls** — `GyroToWall()` drives forward holding heading until the *side* ultrasonic drops below 120 mm (a limiter passing the sensor); two short `GyroDeg` legs then step between the limiters, so the gap (randomised each run) is *measured*, not assumed.
3. **Datum and reverse in** — `ThetaReset(±90)` re-datums the estimator to the bay axis; the car creeps forward until `Heading()` crosses ~7°, then full lock + `DriveDeg(-450, ±100)` reverses along the first arc, opposite lock + `DriveDeg(-480, ∓100)` swings the tail in, then a straightened `GyroDeg(120, 0)` nudges forward to centre.

The two branches (`sign == -1` / `sign == 1`) in [`FeObstacle.py`](src/hub/FeObstacle.py) are mirror images of each other for the two possible lap directions.

The car turns ~1080° over three laps and twelve corners before it ever sees the bay. A heading source losing just 0.3°/corner (invisible on lap 1) arrives 3.6° wrong — enough for a 450-encoder-degree reverse arc to walk the tail sideways into a limiter, in a gap only ~1.5 vehicle-lengths wide. With the Lagrange integrator (≈0.03°/corner) the same twelve corners contribute a few tenths of a degree total, so the hand-tuned arc distances stay valid run after run.

Full source: [`src/hub/FeObstacle.py`](src/hub/FeObstacle.py).

## 7. Repository / build instructions

* **Mechanical assembly** — see the [step-by-step construction guide](construction-guide/) for the full rear-camera → upper-chassis → lower-chassis build order.
* **Hub code** ([`src/hub/`](src/hub/)) is written for **Pybricks** running on the LEGO SPIKE Prime Hub.
  * Install the [Pybricks firmware](https://pybricks.com/install/) on the hub, open [Pybricks Code](https://code.pybricks.com/), and upload `FeFunctions.py` alongside whichever entry point you want to run: `FeOpen.py` (Open Challenge), `FeObstacle.py` (Obstacle Challenge), or `FeView.py` (live sensor telemetry over the hub's Bluetooth REPL — useful for debugging without re-flashing).
* **Camera code** ([`src/camera/`](src/camera/)) is written in **MicroPython** for the Matrix Robotics M-Vision Cam (OpenMV-based).
  * Flash with the [OpenMV IDE](https://openmv.io/pages/download), then upload `main.py` and `LPF2.py` to the camera's filesystem so it boots straight into vision mode and starts emulating a LEGO UART sensor for the hub.
* No external Python packages are required beyond what ships with Pybricks / OpenMV firmware.

## 8. Future Improvements

**Software & reliability**
- Dual-controller architecture (Raspberry Pi for vision + Arduino for real-time motor control) for parallel processing and deterministic timing.
- Lightweight neural-network vision to replace hand-tuned color thresholds.
- External 9-axis IMU for better drift correction.
- Robust UART communication: packet retransmission, timestamps, command validation.
- Expanded watchdogs (ultrasonic/IMU/encoder staleness + auto re-calibration) and crash detection/recovery via accelerometer spikes.
- Automatic retry logic for sensor failures/timeouts.
- Profiling and optimizing critical loops; centralized tunable-parameter config file.
- Structured, real-time logging; backup wall-following/waypoint navigation modes.

**Hardware**
- Rigid custom 3D-printed chassis to reduce flex and improve steering precision.
- Higher-torque motors for more consistent parking.

**Testing & debugging**
- Web-based telemetry dashboard (live video, sensor data, remote tuning).
- Unit tests for `ThetaUpdate()`, `SteerTo()`, `ReadCam()`.

## 9. Conclusion

This robot is the result of an iterative engineering process: build something that works, test on the real field, find a concrete failure, fix it, test again. Every design choice — from steering geometry and sensor placement to the chassis structure and the heading estimator — was driven by data from that loop rather than decided on paper in advance.

The robot can currently complete both the Open and Obstacle challenges reliably; future work will focus on reducing chassis weight, optimizing the drivetrain, improving the vision pipeline, and continuing to refine the control software for speed and accuracy. This documentation is meant to let anyone understand, reproduce and extend what we built.

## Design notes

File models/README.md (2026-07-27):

3D models
====

This directory contains the files used by 3D printers (and any laser-cutting/CNC files) to produce the vehicle's custom parts — the rear camera mast/mount, counterweight box, and other PLA-printed brackets described in the [main README](../README.md#3-mobility-and-mechanical-design).

Full CAD render

| File | Purpose |
|---|---|
| `XLR8 - Future Engineers main design.io` | Full CAD assembly (source project) |
| `Ultra_adapter.STEP` | Ultrasonic sensor mount |
| `Camera adapter.stl` | Rear camera mast/mount, ready to print |
| `Multifunctional parts.stl` | Misc. PLA-printed brackets/connectors |

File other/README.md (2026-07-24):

Other supporting material
====

Supporting figures referenced from the [main README](../README.md), organized by topic:

* [`mechanical-design/`](mechanical-design/) — chassis/camera-mount diagrams, wheel models, Ackermann geometry, gear layout.
* [`iteration-history/`](iteration-history/) — photos of the version 1 → version 2 → final chassis progression.
* [`power-and-sensors/`](power-and-sensors/) — camera and ultrasonic sensor reference photos.
* [`software-and-vision/`](software-and-vision/) — game-mat annotation, control-flow diagrams, and the Lagrange-theta accuracy/parking figures discussed in [§6](../README.md#6-systems-thinking-and-engineering-decisions).

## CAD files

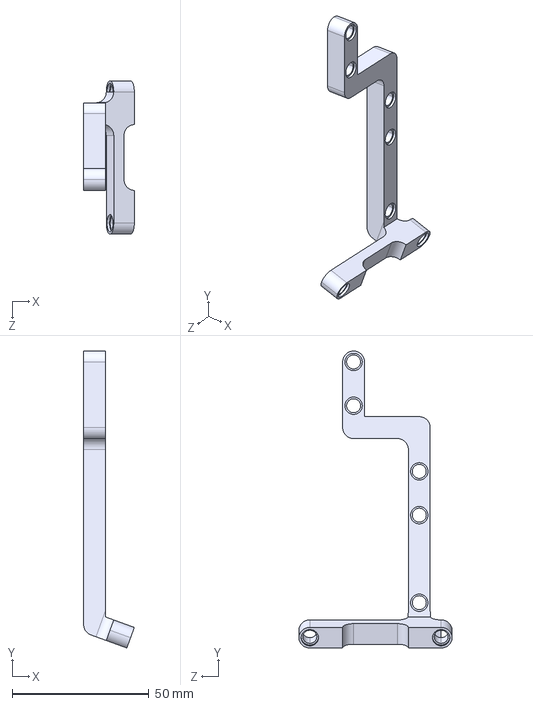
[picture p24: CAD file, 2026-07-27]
models/Ultra_adapter.STEP
18.5 x 108.5 x 56.0 mm

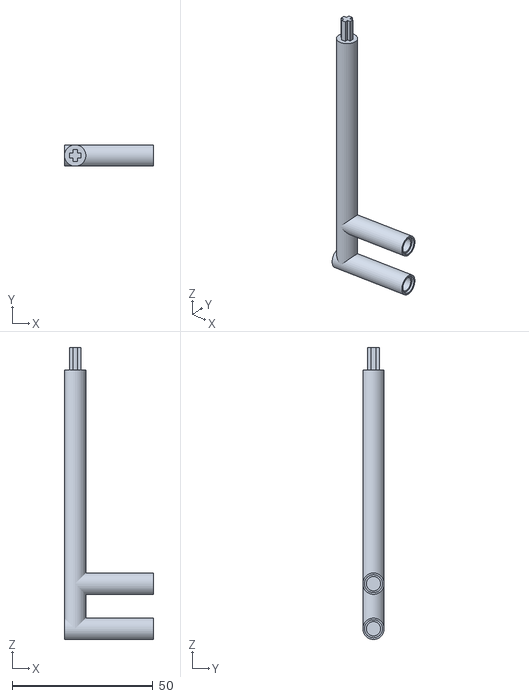
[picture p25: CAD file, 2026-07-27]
models/Camera adapter.stl
31.6 x 7.60 x 103.6

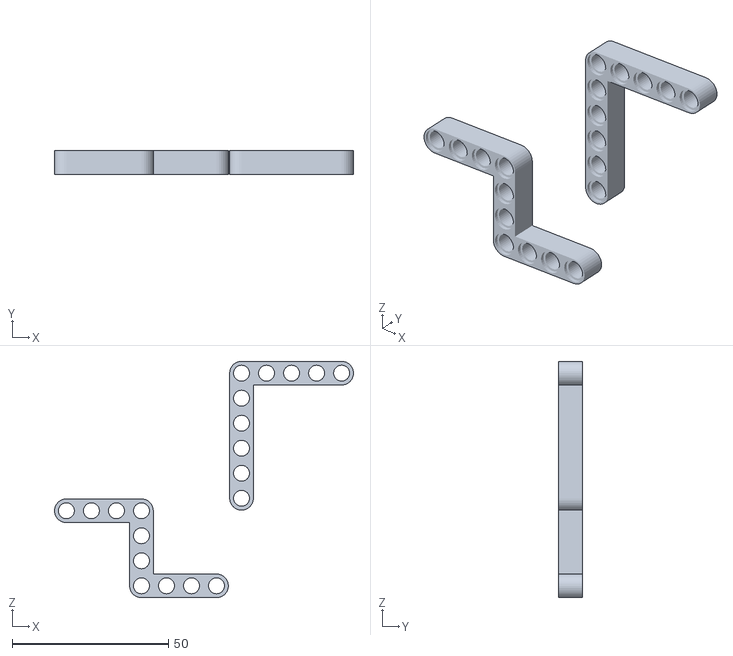
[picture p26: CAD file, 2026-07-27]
models/Multifunctional parts.stl
95.6 x 7.60 x 75.6

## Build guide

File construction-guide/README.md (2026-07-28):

Robot's Detailed Construction Guide
====

This guide is a comprehensive, step-by-step walkthrough of the assembly of our autonomous robot for the **2026 WRO Future Engineers** competition. The assembly is organized into individual modules — the rear camera mount, the main chassis, and other key subsystems. Each section describes the assembly procedure and the connections between components, enabling readers to understand the robot's structure and accurately reproduce the complete model.

## Assembly overview

The robot consists of three main sections:

* **Rear Camera Assembly** — 1 Matrix M-Vision Camera mounted on a support structure constructed from LEGO Technic beams and connectors.
* **Upper Chassis** — 1 LEGO SPIKE Prime Hub with a rechargeable battery, 2 LEGO SPIKE Prime Large Angular Motors, and 2 ultrasonic sensors, all mounted using LEGO Technic connectors and structural reinforcement components.
* **Lower Chassis** — 4 LEGO Technic wheels (56 × 14 mm), 1 LEGO SPIKE Prime Color Sensor, and the drivetrain consisting of LEGO Technic gears, axles, and connector elements.

## Step 1: Preparing the 3D-printed parts

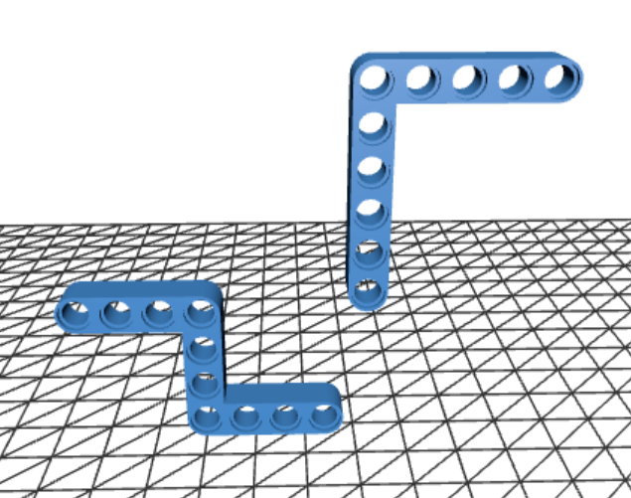
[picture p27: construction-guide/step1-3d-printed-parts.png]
3D-printed L-shaped connectors


These two components are the only **custom 3D-printed parts** used in our robot and are essential to its overall mechanical design. They serve as key structural elements that integrate multiple assemblies into a single rigid framework while providing the precise geometry required for the robot's operation. No existing LEGO Technic components can adequately replace these parts without compromising the robot's structural integrity, stability, or functionality. Their use enables a more compact, robust, and reliable design while preserving seamless integration with the surrounding LEGO Technic system.

The CAD source files for these 3D-printed components are in [`../models/`](../models/).

**Material recommendations.** All custom parts for our robot are 3D-printed using PLA filament. PLA was chosen for its ease of printing, good dimensional accuracy, and sufficient strength for our application. The main chassis, motor mounts, sensor brackets, and camera support mast are all printed in PLA, as the material provides adequate rigidity and impact resistance for the robot's operational loads while remaining lightweight. PLA also allows for fast iteration during testing, enabling us to refine designs quickly between practice sessions.

## Step 2: Assembling the rear camera-mounted section

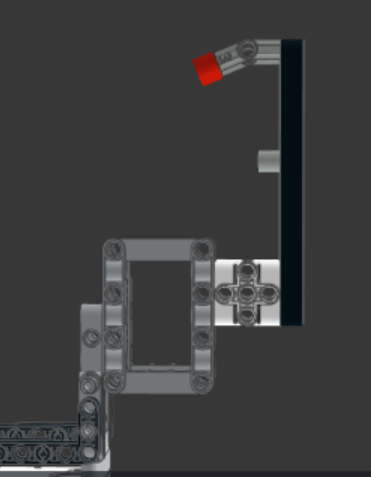
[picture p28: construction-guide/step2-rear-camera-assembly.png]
Rear camera assembly


The rear camera assembly is the simplest subsystem to construct, as it is mechanically independent from the main chassis and consists of only a small number of components. Its modular design also simplifies both assembly and maintenance.

The assembly begins by connecting two LEGO Technic Liftarm Thick 1 × 13 beams using a LEGO Technic Liftarm Thick 1 × 5 beam, forming the primary support structure. At the lower end of this structure, the counterweight — constructed from a LEGO Technic Liftarm, Modified Frame Thick 5 × 7 Open Center — is secured using two LEGO Technic Pin Connector Blocks (1 × 3 × 3) to provide additional rigidity and improve the overall stability of the camera mount. Finally, the camera is installed at the top of the assembly using two LEGO Technic Axle and Pin Connectors (157.5°) together with a LEGO Technic Liftarm Thick 1 × 7, which forms a rigid and elevated camera mount. This configuration provides stable support for the camera while minimizing vibrations during robot operation.

## Step 3: Assembling the upper chassis section

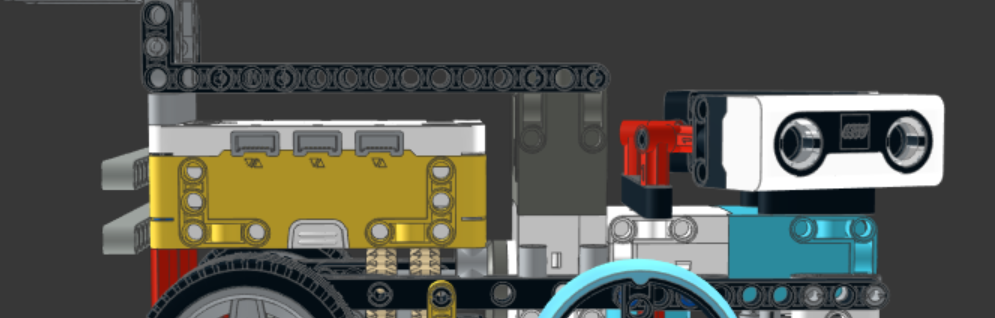
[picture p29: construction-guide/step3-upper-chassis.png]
Upper chassis assembly


The upper chassis assembly is the second most complex subsystem of the robot. Although it integrates several major electronic and structural components, its modular design allows it to be assembled efficiently by following the steps outlined below.

Assembly begins with the LEGO SPIKE Prime Hub, equipped with its rechargeable battery, which serves as the central structural and control unit of the robot. The previously assembled rear camera module is then attached to the rear of the hub using the two custom PLA 3D-printed L-shaped connectors described earlier. To further improve rigidity, two LEGO Technic Liftarm Thick 1 × 13 beams are installed on both sides of the connection, forming a robust interface between the main chassis and the elevated camera assembly.

An additional pair of LEGO Technic Liftarm Thick 1 × 13 beams is mounted behind the SPIKE Prime Hub to prevent unwanted movement of the hub during operation. These beams reinforce the rear section of the chassis, ensuring that the hub remains securely fixed despite vibrations and dynamic loads encountered while the robot is moving.

At the front of the hub, the primary LEGO SPIKE Prime Large Angular Motor is installed. This motor is connected to the hub using the previously mentioned 1 × 13 beams together with two LEGO Technic Liftarm Thick 1 × 15 beams positioned underneath. Besides securing the motor, these structural members act as the primary bridge between the front and rear sections of the robot, significantly increasing the rigidity of the chassis.

Finally, the second LEGO SPIKE Prime Large Angular Motor, together with the two ultrasonic sensors, is assembled at the front of the chassis. The ultrasonic sensors are mounted directly above the motor using a LEGO Technic Liftarm Thick 1 × 9, four angled pin connectors, and a LEGO Technic Bent Liftarm Thick L-shaped 2 × 4. This arrangement provides a stable mounting platform while maintaining accurate sensor alignment. The steering motor is further connected to the rest of the chassis by two additional 1 × 9 liftarms positioned on either side, creating a rigid structural bridge that integrates the front assembly with the remainder of the robot. This design ensures that both the steering mechanism and the sensors remain securely aligned, contributing to reliable navigation and consistent performance throughout operation.

## Step 4: Assembling the lower chassis section

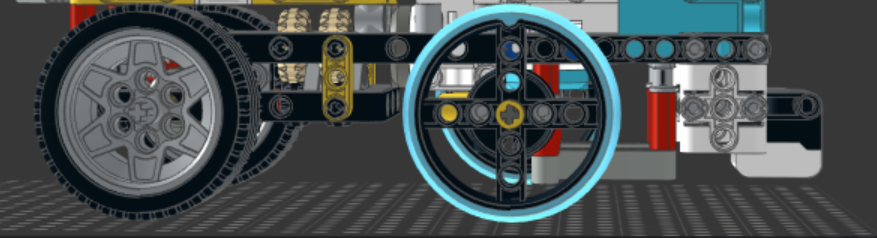
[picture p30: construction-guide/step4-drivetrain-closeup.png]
Drivetrain closeup


The lower chassis assembly is the most intricate subsystem of the robot and requires the greatest level of precision during assembly. It incorporates the drivetrain, steering mechanism, and line-following sensor, all of which must be accurately aligned to ensure reliable operation. The primary structure is built around a LEGO Technic Open Frame 7 × 11, reinforced by two LEGO Technic Liftarm Thick 1 × 11 beams at the front to provide a rigid and stable foundation for the entire lower chassis.

Assembly begins with the rear-wheel drivetrain. The two 62.4 mm LEGO Technic tires are mounted on a shared axle approximately 10 cm in length. A series of three interconnected gears transfers rotational power efficiently from the drive motor to both rear wheels, ensuring synchronized rotation and smooth propulsion while maximizing the drivetrain's mechanical efficiency.

The rear drivetrain is then connected to the front steering assembly through a compact gear transmission consisting of four adjacent gears. Rather than transmitting propulsion, this gear train transfers the steering motion generated by the steering motor to the front axle, allowing both front wheels to rotate simultaneously while maintaining the Ackermann steering geometry (see [main README §3](../README.md#3-mobility-and-mechanical-design) for the full derivation).

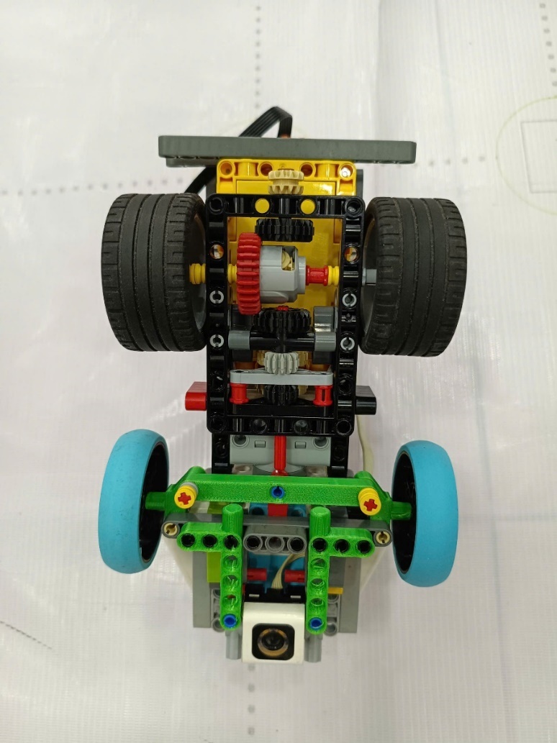
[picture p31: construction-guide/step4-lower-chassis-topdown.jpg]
Lower chassis, top-down


The front wheel assembly consists of two 49.5 mm LEGO SPIKE Prime wheels connected by a common steering axle. This axle is directly linked to the steering motor mounted in the upper chassis, enabling precise and synchronized steering of both front wheels. The steering linkage is carefully configured to implement Ackermann steering geometry, improving cornering accuracy and reducing wheel slip during turns.

Finally, the LEGO SPIKE Prime Color Sensor is installed at the front of the lower chassis. In addition to providing reliable line detection, its mounting structure is integrated with the front steering assembly, increasing the rigidity of the front chassis and improving the overall structural integrity of the robot. Together, these components form a compact, robust, and mechanically stable lower chassis capable of delivering precise steering, efficient propulsion, and reliable sensor performance throughout the competition.

## Final step: software and wiring

Integrate the software, control algorithms, and wiring system described in [`../src/`](../src/) into the assembled robot. Once all electrical connections have been completed and verified, upload the program to the LEGO SPIKE Prime Hub and perform system checks to ensure that all sensors, motors, and electronic components communicate correctly and operate as intended.

Upon completing the four assembly stages, the robot is fully constructed and ready for electrical integration, software deployment, and performance testing. The modular design of each subsystem allows individual components to be assembled, inspected, and replaced independently, simplifying both maintenance and future design iterations.

Throughout the construction process, particular attention should be given to the alignment of the drivetrain, steering mechanism, and sensors, as even minor assembly inaccuracies can affect the robot's overall performance. By following the procedures described in this guide, readers should be able to accurately reproduce our robot and obtain a mechanically stable platform suitable for autonomous operation.

See the [main README](../README.md) for the robot's electrical architecture, wiring layout, and software implementation — how the assembled hardware is integrated into a fully functional autonomous system.

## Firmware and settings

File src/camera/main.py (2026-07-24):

import sensor, image, time
import gc, utime
import micropython
import LPF2
from machine import Pin
from pyb import LED
micropython.alloc_emergency_exception_buf(200)

# ---------------- Color thresholds ----------------
# Format: (L_min, L_max, A_min, A_max, B_min, B_max)
# Index 0 -> RED, Index 1 -> GREEN.  This list order defines the colour ID:
#   colour 0 = red, colour 1 = green
red_threshold   = (20, 55, 38, 80, 13, 64)   # red block
red_threshold_2 = (10, 41, 23, 67, 5, 54) # red block darkened
red_threshold_3 = (0, 41, -10, 57, -5, 38) # red block darkened
green_threshold = (10, 65, -60,  -10,  25, 60)   # green block
black_threshold = (0, 45, -20, 5, -10, 20)
white_threshold = (55, 75, -10, 20, -15, 15)
thresholds = [red_threshold, green_threshold, red_threshold_2,  red_threshold_3]

#Define the middle ROI
mid_roi = (130, 40, 60, 40)
mid_roi2 = (90, 130, 140, 50)
mid_roi3 = (70, 90, 180, 50)
white_roi = (70, 100, 180, 100)

# ---------------- Caamera setup ----------------
sensor.reset()
sensor.set_vflip(True)
sensor.set_hmirror(True)
sensor.set_pixformat(sensor.RGB565)       # Format: RGB565
sensor.set_framesize(sensor.QVGA)         # Size: QVGA (320 x 240)
sensor.set_auto_gain(False)               # MUST be OFF for stable colour tracking
sensor.set_auto_whitebal(False)           # MUST be OFF for stable colour tracking
clock = time.clock()                      # Clock object to track the FPS

# ---------------- LUMP / LPF2 setup ----------------
# We send 4 x Int16 values: [X, Y, colour, count]  -> 8 bytes (a clean power of 2)
#   X      : centre x of the chosen block (0..320), 0 if none
#   Y      : centre y of the chosen block (0..240), 0 if none
#   colour : 0 = red, 1 = green, -1 = no block detected
#   count  : total number of red+green blocks seen this frame
modes = [LPF2.mode('OpenMV-ALL', size=4, type=LPF2.DATA16, format='3.0'),]
DataToSend = [0, 0, 0, 0]                # X, Y, colour, count
lpf2 = LPF2.Prime_LPF2(3, 'P4', 'P5', modes, 62, timer=4, freq=10)
lpf2.initialize()

# ---------------- Main loop ----------------
while True:
    # If the LEGO brick is not connected, re-initialise
    if not lpf2.connected:
        LED(1).on()           # Red LED = not connected
        LED(2).off()
        LED(3).off()
        lpf2.sendTimer.deinit()
        utime.sleep_ms(50)
        lpf2.initialize()
    else:

        clock.tick()
        img = sensor.snapshot()
        # Black out the top strip (beyond the game field) so its background
        # noise can never form a blob. Must be done BEFORE find_blobs().
        img.draw_rectangle(0, 0, 320, 30, color=(0, 0, 0), fill=True)
        img.draw_rectangle(80, 200, 160, 40, color=(0, 0, 0), fill=True)
        blobs = img.find_blobs(thresholds, area_threshold=92, pixels_threshold=92)


        # --- MID ROI ---
        mid_blobs = img.find_blobs([black_threshold], roi=mid_roi, pixels_threshold=5, area_threshold=5, merge=True)
        mid_black_pixels = sum([b.pixels() for b in mid_blobs])
        mid_total_pixels =  mid_roi[2] *  mid_roi[3]
        mid_black_percent = ( mid_black_pixels /  mid_total_pixels) * 180


        # --- MID ROI2 ---
        mid_blobs2 = img.find_blobs([black_threshold], roi=mid_roi2, pixels_threshold=5, area_threshold=5, merge=True)
        mid_black_pixels2 = sum([b.pixels() for b in mid_blobs2])
        mid_total_pixels2 =  mid_roi2[2] *  mid_roi2[3]
        mid_black_percent2 = ( mid_black_pixels2 /  mid_total_pixels2) * 120

        # --- MID ROI3 ---
        mid_blobs3 = img.find_blobs([black_threshold], roi=mid_roi3, pixels_threshold=5, area_threshold=5, merge=True)
        mid_black_pixels3 = sum([b.pixels() for b in mid_blobs3])
        mid_total_pixels3 =  mid_roi3[2] *  mid_roi3[3]
        mid_black_percent3 = ( mid_black_pixels3 /  mid_total_pixels3) * 100



        # # Draw the MID ROI box on the IDE preview (blue outline)
        img.draw_rectangle(mid_roi, color=(0, 0, 255))
        img.draw_rectangle(mid_roi2, color=(0, 0, 255))
        img.draw_rectangle(mid_roi3, color=(0, 0, 255))


        max_size    = 0
        block_x     = 0
        block_y     = 0
        block_color = -1      # -1 = nothing found
        count       = 0

        for b in blobs:
            # b.code() tells which threshold(s) this blob matched.
            # bit 0 (value 1) -> red_threshold (index 0)
            # bit 1 (value 2) -> green_threshold (index 1)
            if b.code() & 1 or b.code() & 4 or b.code() & 8:
                color = 0                 # red
                draw_col = (255, 0, 0)
            elif b.code() & 2:
                color = 1                 # green
                draw_col = (0, 255, 0)
            else:
                continue

            # Density (extent) = blob pixels / bounding-box area. A solid block
            # sits near 1.0; ragged background noise is much lower. Only blobs
            # that fill at least 80% of their bounding box qualify.
            if b.density() < 0.5 and b.code() & 2:
                continue
            if b.density() < 0.6 and b.code() & 8:
                continue
            if b.density() < 0.65 and (b.code() & 1 or b.code() & 4):
                continue
            if b.area() < 200:
                continue
            if b.w()/b.h() > 0.9:
                continue
            if (mid_black_percent3 > 60) and b.y() < 80:
                continue
            # if w_percent < 30:
            #     continue

            # Debug drawing on the IDE preview
            img.draw_rectangle(b.rect(), color=draw_col)
            img.draw_cross(b.cx(), b.cy(), color=draw_col)
            count += 1

            # Keep the largest blob = the closest / most relevant block
            if b.cy() > block_y:
                max_size    = b.area()
                block_x     = b.cx()
                block_y     = b.cy()
                block_color = color



        img.draw_string(1, 1, "X:%d Y:%d C:%d N:%d FPS:%d" %
                        (block_x, block_y, block_color, count, int(clock.fps())))

        LED(1).off()
        LED(2).off()
        LED(3).off()

        mid_black_percent = max(mid_black_percent, mid_black_percent2) if count == 0 else mid_black_percent2


        DataToSend = [block_x, block_y, block_color, int(mid_black_percent)]

        # print (block_x, block_y, block_color, count, max_size)
        # Send the data to the Spike Prime hub
        if lpf2.current_mode == 0:
            lpf2.load_payload('Int16', DataToSend)

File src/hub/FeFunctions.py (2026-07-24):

from pybricks.hubs import PrimeHub
from pybricks.pupdevices import Motor, ColorSensor
from pybricks.parameters import Axis, Button, Color, Direction, Port, Stop
from pybricks.tools import wait, StopWatch
from pybricks.iodevices import PUPDevice

# ---------------- Hub ----------------
hub = PrimeHub()
hub.system.set_stop_button(Button.BLUETOOTH)
hub.speaker.volume(50)

clock = StopWatch()

Drive  = Motor(Port.B, Direction.COUNTERCLOCKWISE)
Steer  = Motor(Port.C, Direction.COUNTERCLOCKWISE)
Camera = PUPDevice(Port.A)
ColorSens = PUPDevice(Port.E)
UltraL = PUPDevice(Port.F)
UltraR = PUPDevice(Port.D)

CAM_MODE  = 0
IMG_W     = 320
IMG_H     = 240
CENTER_X  = 160

RED, GREEN, NONE = 0, 1, -1

# ---------------- Behaviour targets ----------------
APPROACH_Y     = 130   # y at which the side target reaches its FULL value
TARGET_X_GREEN = 310   # green target when the block is close (y >= APPROACH_Y)
TARGET_X_RED   = 10    # red   target when the block is close
WALL_THRES = 500
BLACK_IDX   = 3
BLACK_THRES = 60
BLACK_TURN  = -1000

# ---- Approaching x-target ramp ----
# As a block approaches (y grows), shift the x-target from a milder "far" value
# up to the full side target by APPROACH_Y, so the car eases over early.
Y_RAMP_START = 35      # y where ramping begins (block just clears the top mask)
GREEN_FAR    = 200     # green target when far  -> ramps to TARGET_X_GREEN by APPROACH_Y
RED_FAR      = 120     # red   target when far  -> ramps to TARGET_X_RED   by APPROACH_Y

# ---------------- Steering tuning ----------------
STEER_KP     = 1.5
STEER_SIGN   = -1
STEER_LOAD_CAP = 70
OPEN_KP = 0.018
OPEN_KD = 0
OBSTACLE_KP = 0.05
GYRO_FLIP = 15   # flip the ultrasonic centring once the body is rotated more than this (deg) off the corridor

# ---------------- Drive tuning ----------------
DRIVE_FWD = 70

# ---------------- Utils ----------------
def clamp(v, lo, hi):
    return lo if v < lo else hi if v > hi else v

# =====================================================================
#  LAGRANGE-INTERPOLATED THETA (yaw displacement from angular velocity)
# =====================================================================
# Instead of trusting hub.imu.heading() directly (its internal fusion can
# absorb 3 laps worth of vibration noise, wrap-arounds and micro-jumps),
# we rebuild the yaw angle ourselves:
#
#     theta(T) = theta(0) + integral( omega(t) dt )  from 0 to T
#
# omega(t) = hub.imu.angular_velocity(Axis.Z) is sampled every control
# loop (~10 ms, but NOT at perfectly regular intervals - Bluetooth,
# camera reads and garbage collection all jitter the loop period).
# A plain rectangle sum  theta += omega * dt  is only 1st-order accurate
# and the jitter makes it worse.  So we fit a LAGRANGE POLYNOMIAL of
# degree 3 through the last 4 samples (t_i, w_i) and integrate it
# EXACTLY over the newest interval.
#
# We build the polynomial in NEWTON DIVIDED-DIFFERENCE form:
#
#   P(t) = d0 + d1(t-t0) + d2(t-t0)(t-t1) + d3(t-t0)(t-t1)(t-t2)
#
# which is the same unique cubic as the classical Lagrange basis form,
# but is far cheaper to build and - crucially - can be expanded into
# ordinary coefficients c0..c3 and integrated with a plain antiderivative:
#
#   INT P dt = c0*t + c1*t^2/2 + c2*t^3/3 + c3*t^4/4
#
# evaluated at the two ends of the newest interval.  No quadrature rule
# and no magic constants are needed: the integral of a cubic is just
# another polynomial, so this is exact arithmetic, not an approximation.
#
# Uneven time steps cost nothing (the t_i appear explicitly), single
# noisy samples are averaged against their neighbours by the fit, and
# the result is 4th-order accurate instead of 1st.
# =====================================================================

THETA_N        = 4       # samples in the sliding window -> cubic Lagrange
OMEGA_DEADBAND = 0.5     # deg/s, kills stand-still gyro hiss so theta
                         # cannot creep while the robot is parked

theta_clock = StopWatch()    # DEDICATED clock: GyroDeg() etc. reset the
                             # shared 'clock', which would corrupt t_i
_theta_ts   = []             # ring buffer of sample times   t_i  [s]
_theta_ws   = []             # ring buffer of sample omegas  w_i  [deg/s]
_theta      = 0.0            # accumulated yaw displacement [deg]
_omega_bias = 0.0            # gyro bias measured at start-up [deg/s]

def _integrate_cubic(ts, ws):
    """Exact integral of the cubic through the 4 points (ts, ws), taken
    over the NEWEST interval [ts[2], ts[3]].

    Step 1: Newton divided differences d0..d3.
    Step 2: expand to ordinary coefficients c0..c3.
    Step 3: evaluate the antiderivative at both ends.
    All three steps are plain arithmetic - no quadrature nodes."""
    t0, t1, t2, t3 = ts
    w0, w1, w2, w3 = ws

    # --- divided differences (the Newton coefficients) ---
    d0 = w0
    d1 = (w1 - w0) / (t1 - t0)
    d12 = (w2 - w1) / (t2 - t1)
    d2 = (d12 - d1) / (t2 - t0)
    d23 = (w3 - w2) / (t3 - t2)
    d3 = ((d23 - d12) / (t3 - t1) - d2) / (t3 - t0)

    # --- expand P(t) into c0 + c1 t + c2 t^2 + c3 t^3 ---
    c3 = d3
    c2 = d2 - d3 * (t0 + t1 + t2)
    c1 = d1 - d2 * (t0 + t1) + d3 * (t0*t1 + t0*t2 + t1*t2)
    c0 = d0 - d1 * t0 + d2 * t0*t1 - d3 * t0*t1*t2

    # --- antiderivative, Horner form: F(x) = ((((c3/4)x + c2/3)x + c1/2)x + c0)x
    def F(x):
        return ((((c3 * 0.25 * x + c2 / 3.0) * x + c1 * 0.5) * x) + c0) * x

    return F(t3) - F(t2)

def ThetaCalibrate(ms=800):
    """Measure the gyro's zero-rate bias.  Call ONCE at program start
    while the robot is perfectly still (before Escape()/Run())."""
    global _omega_bias
    n = 0
    acc = 0.0
    theta_clock.reset()
    while theta_clock.time() < ms:
        acc += hub.imu.angular_velocity(Axis.Z)
        n += 1
        wait(5)
    _omega_bias = acc / n if n else 0.0
    print("gyro bias:", _omega_bias, "deg/s over", n, "samples")

def ThetaReset(value=0.0):
    """Restart the integrator (analogue of hub.imu.reset_heading)."""
    global _theta, _theta_ts, _theta_ws
    _theta = value
    _theta_ts = []
    _theta_ws = []
    theta_clock.reset()
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
